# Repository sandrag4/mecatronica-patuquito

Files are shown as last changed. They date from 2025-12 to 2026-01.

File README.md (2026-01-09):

#  Proyecto de Mecatrónica – *Patuquito*

Este repositorio contiene todo el material necesario para el desarrollo del proyecto de la asignatura de Mecatrónica, cuyo objetivo es diseñar, montar y programar un **robot autónomo con patas**, capaz de **desplazarse y evitar obstáculos**.

El contenido está organizado para que cualquier usuario pueda **replicar**, **comprender** y **utilizar** el robot, ya sea con fines académicos o recreativos.

---

## Estructura del Repositorio

En las siguientes carpetas encontrarás todos los recursos del proyecto:

- [`codigo/`](./codigo/)  
  Contiene todos los códigos desarrollados durante el proyecto. Dentro de esta carpeta se incluyen:

  - [`codigo_robot/`](./codigo/codigo_robot/)  
    Código final utilizado por el robot para ejecutar los distintos modos de funcionamiento y comportamientos programados.

  - [`codigo_validaciones/`](./codigo/codigo_validaciones/)  
    Conjunto de códigos destinados a realizar las distintas pruebas y validaciones del robot, incluyendo test de motores, sensores, botones e inicialización.

- [`documentacion/`](./documentacion/)  
  Contiene los documentos generados durante el desarrollo del proyecto junto con los archivos de las piezas:  
  - **Informe de Autoevaluación** (diario de trabajo, problemas encontrados y soluciones aplicadas)  
  - **Informe Técnico** (documentación completa para replicar el proyecto en casa)  
  - **Manual del Usuario** (instrucciones para montar y utilizar el robot)  
  - **Manual de Mantenimiento** (indicaciones de cuidado y mantenimiento del sistema)
  - [`piezas/`](./documentacion/piezas)  
    Piezas para la impresión 3D
  - [`intentosde simulacion/`](./documentacion/intento_simulacion)  
    Los prototipos anteriores fallidos

- [`enunciado/`](./enunciado/)  
  Carpeta que contiene el enunciado completo del proyecto.

---
## Video

https://urjc-my.sharepoint.com/:v:/g/personal/s_calvo_2022_alumnos_urjc_es/IQALAh5Pe_J5TpLPzdulBIcyASQluEaZyc-CBJwZntN-4Jk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 

---

## Integrantes del Proyecto

- **Sandra González Alonso**  
- **Valeria Stobinski Adillo**  
- **Silvia Calvo Cabello**  
- **Irene Díez de Toro**

---

## Licencia y Uso

Este repositorio es **público** y de **libre acceso** para uso personal, educativo o recreativo.  
No está permitido su uso con fines comerciales ni su venta.

---

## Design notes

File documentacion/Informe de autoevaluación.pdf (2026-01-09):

# INFORME DE AUTOEVALUACIÓN

# PATUQUITO

# Mecatrónica

## IRENE DIEZ DE TORO

## SANDRA GONZALEZ ALONSO

VALERIA STOBINSKI ADILLO (https://www.aulavirtual.urjc.es/moodle/user/view.php?id=244258&course=237750)

## SILVIA CALVO CABELLO

## 4º INGENIERÍA ROBÓTICA SOFTWARE

12-12-2025

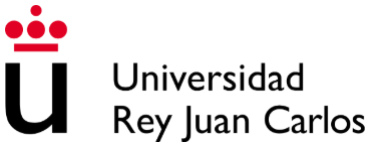
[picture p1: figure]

# Índice

Índice | 2
Planning Semanal | 4
Semana 29 - 9 | 4
- Búsqueda de robots con patas (Todas) | 4
Semana 5 - 10 | 4
- Primeros bocetos del robot (Todas) | 4
Semana 13 - 10 | 5
- Cálculo de motores, baterías y material necesario: (Silvia) | 5
- Distintos mecanismos del movimiento (Valeria y Irene) | 5
Semana 27 - 10 | 7
- Encontrar las baterías /pilas necesarias: (Silvia) | 7
- Diseño basico en blender sin mecanismo y probarlo en pybullet (preanálisis)
(Silvia, Sandra) | 7
- Diseño basico en blender con mecanismo y probarlo en pybullet (preanálisis)
(objetivo patucos) (Irene, Sandra, Valeria) | 7
- Diseño en blender de las piezas para imprimir (Sandra) | 8
- Diseñar cabeza y giro y hueco de la carga (Irene y Valeria) | 8
- Diseño del cableado (Silvia) | 9
Semana 3 - 11 | 9
- Planos mecánicos: (Sandra) | 9
Semana 10 - 11 | 9
- Programación patas: (Silvia) | 9
- Programación cabeza (Sandra) | 9
- Diseño eléctrico: (Irene y Valeria) | 9
Semana 17 - 11 | 10
- Programación: lógica del proyecto : (Sandra y Silvia) | 10
- Montaje del robot: (Todas) | 10
- Rediseño del engranaje: (Sandra) | 10
- Empezar con la documentación de los manuales (Silvia) | 10
Semana 24 -11 | 10
- Seguir con la documentación de los manuales (Silvia,Valeria,Irene) | 10
- Programación patas (Valeria y Sandra) | 11
- Rediseño de las patas (Valeria y Sandra) | 11
- Prueba de las pruebas (Sandra y Silvia) | 11
Semana 1-12 | 11
- Programación patas (Sandra) | 11
- Lijado de piezas (Todas) | 11
- Taladrar hueco para la segunda cabeza (Sandra y Valeria) | 12
- Diseño segunda cabeza (Irene) | 12
- Seguir con la documentación (Irene y SIlvia) | 12
- Programación segunda cabeza (Sandra) | 12
Semana 8-12 | 12
- Programación tocar pared (Sandra) | 12

- Planos restantes (Sandra y Silvia) | 13
Semana 15-12 | 13
- Terminar con la documentación (Irene y Silvia) | 13
Semana 5-1 | 13
- Terminar el montaje y pruebas (Sandra, Valeria, Irene, Silvia) | 13
Resumen | 14
1. Sandra González Alonso 9/10 | 14
2. Silvia Calvo Cabello 8/10 | 14
3. Valeria Stobinski Adillo 8/10 | 14
4. Irene Díez de Toro 8/10 | 15

# Planning Semanal

## Semana 29 - 9

- Búsqueda de robots con patas (Todas)
- Se realizó un estudio para investigar diferentes tipos de robots con patas. Sin embargo, muchos de ellos requerían un gran número de motores por pata, lo que resultaba en sistemas complejos y menos eficientes. A continuación se presentan algunos ejemplos:
- 1. Robots tipo perro
Ejemplo: Perro robótico Unitree Go2 Pro
Este tipo de robot tiene 3 grados de libertad en cada pata, lo que significa que necesita un total de 12 motores para el movimiento. Este número de motores, aunque efectivo, resulta ser excesivo y difícil de manejar en términos de eficiencia y diseño.
- 2. Robots tipo araña
Ejemplo: Araña robótica
Al igual que el robot tipo perro, el robot tipo araña también tiene 3 grados de libertad en cada pata, sumando un total de 12 servomotores para las 4 patas. Aunque el diseño permite una gran flexibilidad, el alto número de motores sigue siendo un desafío en términos de peso y consumo de energía.
- 3. Patas y arquitectura propuesta por Valeria
En este caso, se optó por un diseño basado en un sistema de patas que optimiza el número de motores, manteniendo la versatilidad y estabilidad del robot, pero con menos componentes. https://www.youtube.com/watch?v=iVVLTqdiBNI
- Enfoque hexápodo
Después de analizar estos diseños, decidimos optar por un enfoque basado en el movimiento hexápodo, tal como se muestra en el siguiente video. Este diseño permite controlar el movimiento de la estructura con un solo motor, lo que a su vez facilita el control de dos ejes de movimiento simultáneamente. Esto no solo reduce el número de motores necesarios, sino que mejora la eficiencia y la simplicidad del sistema en comparación con los enfoques previos.

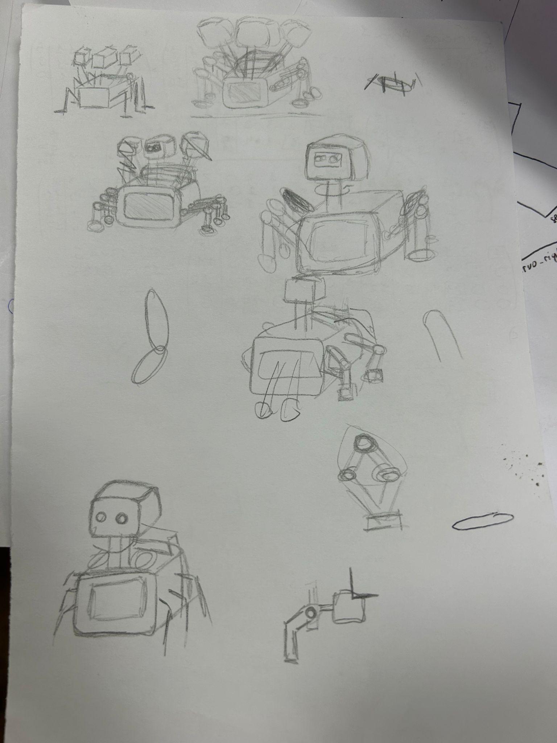
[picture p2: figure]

## Semana 5 - 10

- Primeros bocetos del robot (Todas)
La idea inicial era diseñar unas patas móviles, pero al analizarlo vimos que se requería un control demasiado complejo y un número elevado de motores para lograr el movimiento deseado. Por ello, se optó por adoptar un desplazamiento similar al de los escorpiones, utilizando cinco patas para aumentar la estabilidad. A partir de esta decisión se elaboraron los bocetos correspondientes al nuevo sistema.

En este diseño, las patas podían ser fijas y el movimiento dependía de la coordinación de tres pares, organizados en dos grupos que se desplazan de forma síncrona pero con un desfase entre ellos.

En cuanto a la cabeza, para facilitar en análisis del entrono, se querían hacer 3 cabezas. Primero era hacer 3 lineales, después se intentó desplazarlas hacia los lados y hacia atrás. A final con un sistema de rotación de cabeza y para tener más espacio en la tapa para el resto de piezas se optó por mantener solo una cabeza.

## Semana 13 - 10

- Cálculo de motores, baterías y material necesario: (Silvia)
- Se calcularon los motores. Se hicieron varios cálculos y mecanismos de engranajes debido a la disponibilidad de motores que había. Primero calculamos para 6 motores, y un motor por cada pata, luego hablando con el profesor volvimos a calcular los motores para que cada motor soporte 3 patas y un mecanismo de engranajes para moverlos, pero no tenían motores suficientemente potentes para ello. Por lo que volvimos a usar 6 servomotores para facilitar la sincronización de estos.
- Distintos mecanismos del movimiento (Valeria y Irene)

Tras definir el sistema de pares síncronos con desfase (el “sistema escorpión”), se analizó cómo lograr la coordinación del movimiento. Inicialmente se planteó utilizar seis servomotores. Sin embargo, comprobamos que no era necesario un sistema con retroalimentación continua, sino simplemente una coordinación por grupos.

Para reducir el número de motores, se estudió la posibilidad de emplear un mecanismo de engranajes accionado por dos motores, uno a cada lado. No obstante, tras realizar los cálculos y consultar con el responsable del material, se confirmó que no había disponibles motores con la potencia suficiente para este sistema.

Por ello, se decidió volver a la idea original de utilizar seis servomotores, que permiten obtener retroalimentación para una mejor coordinación de las patas, al ser completamente independientes entre sí.

Sistema de engranajes con espaciado y rotación de patas con limitación de movimiento en los ejes

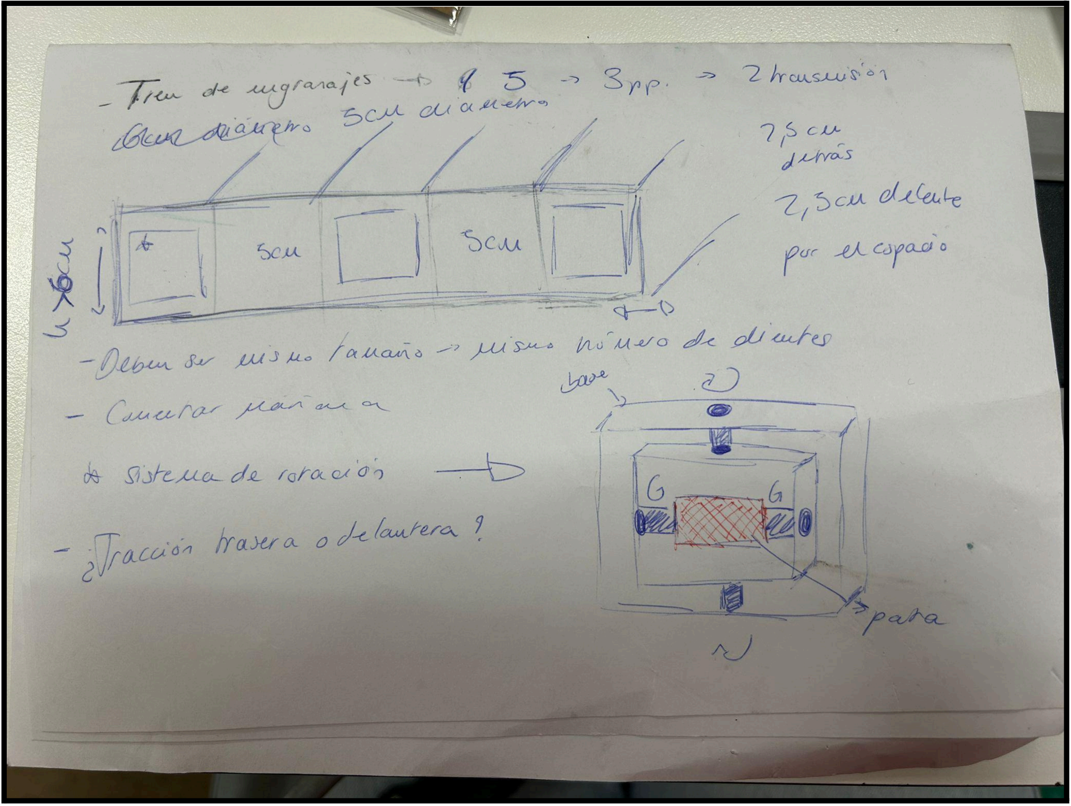
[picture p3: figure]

Diseño del sistema de enganche de pata con engranajes:

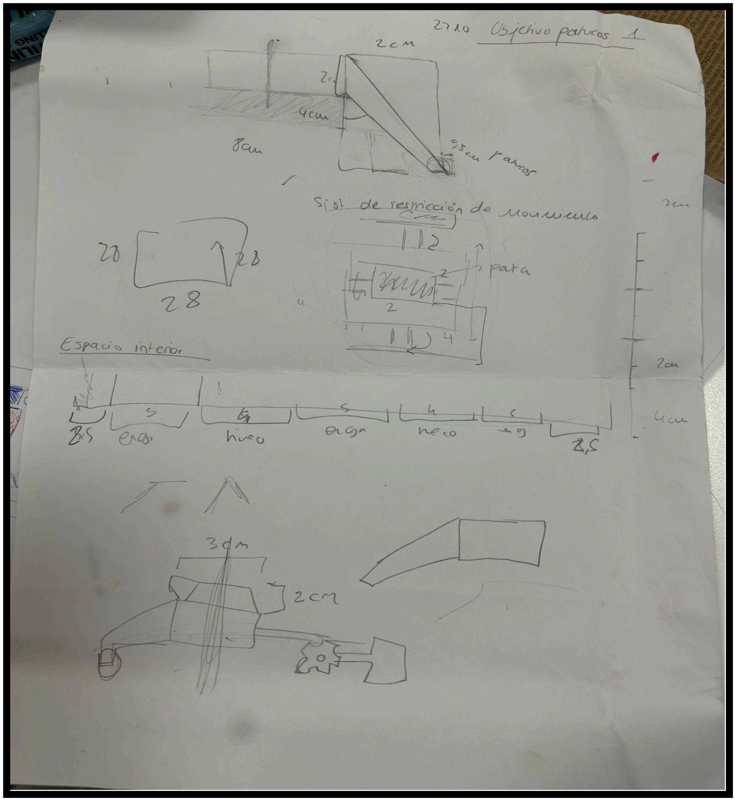
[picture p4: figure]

## Semana 27 - 10

- Encontrar las baterías /pilas necesarias: (Silvia)
- Se calcularon las baterías necesarias para todos los motores y se decidió comprar pilas recargables ya que las baterías necesarias eran de plomo y pesaban demasiado. 6 pilas de 1.2 V
- Diseño basico en blender sin mecanismo y probarlo en pybullet (preanálisis) (Silvia, Sandra)
- No funciona bien porque con un solo servo la pata movía su orientación y necesitábamos que mantuviese orientación del pie de la pata hacia el suelo siempre, conseguimos eso en Blender pero solo poniendo un motor extra que girase en dirección contraria para contrarrestar el giro. La otra solución fue que la pata no estuviese fija al motor y tuviese holgura, el problema de eso es que esa holgura daba demasiada libertad a la pata y se quedaba la pata en horizontal.
- Videos: video1.mp4 (https://urjc-my.sharepoint.com/:v:/g/personal/s_calvo_2022_alumnos_urjc_es/EeDAGlk2rV1Dtp-OM11wCsABKgBpXJ1iR6urnx2pbYHk5w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) video2.mp4 (https://urjc-my.sharepoint.com/:v:/g/personal/s_calvo_2022_alumnos_urjc_es/EaXeEfbVReZFqrjpIT3TwOIBPuNwsKoTI84sSxCdLMh5IQ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)
- Diseño basico en blender con mecanismo y probarlo

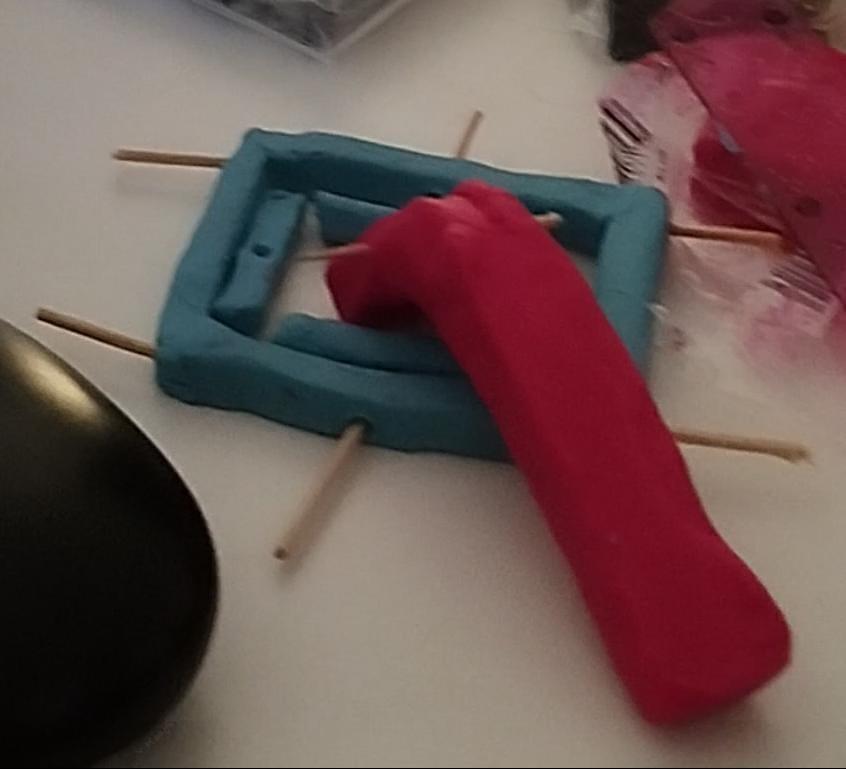
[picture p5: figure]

en pybullet (preanálisis) (objetivo patucos) (Irene, Sandra, Valeria)
- Para poder visualizar espacialmente el diseño 3D, se
compró plastilina con el fin de poder hacer un diseño
inicial de algunas piezas, principalmente las patas y
su mecanismo. Se probó y cambió las medidas de las patas, y de los mecanismos para dejar hueco suficiente para el movimiento de las patas. Una vez

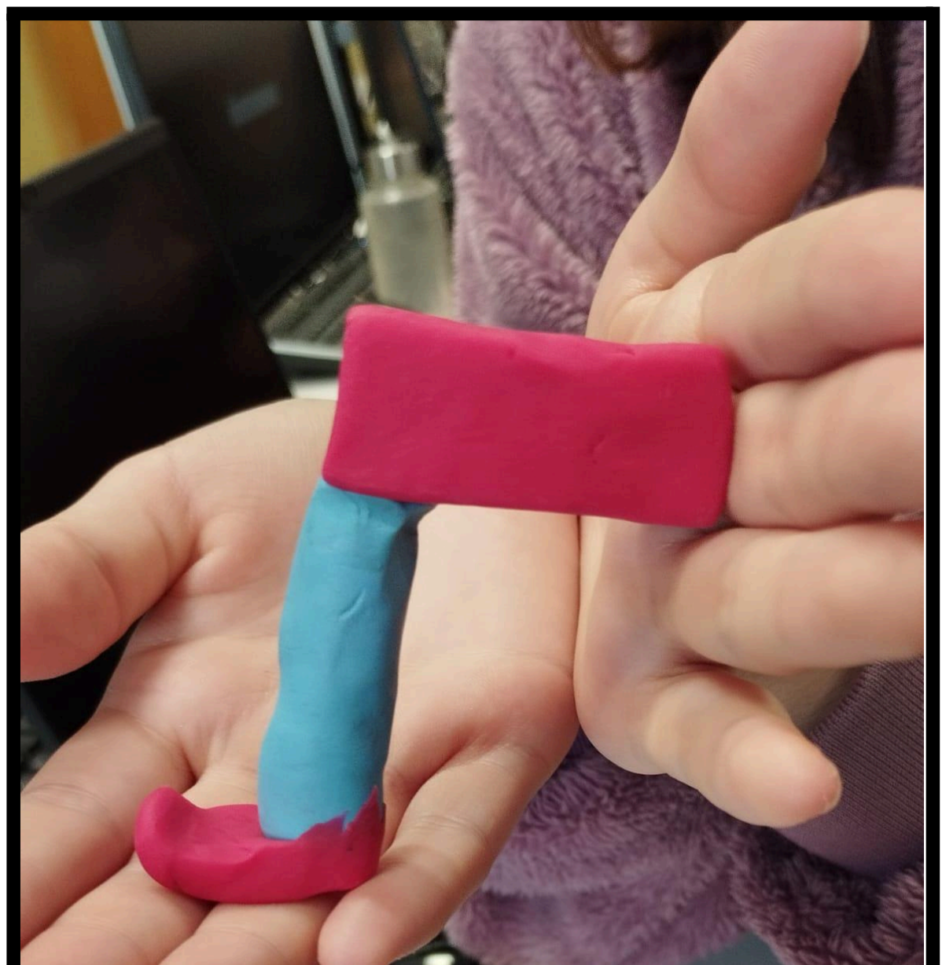
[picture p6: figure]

establecidas unas medidas específicas, después de este proceso, se fueron diseñando estas piezas en blender para probar su funcionamiento.
- Conseguir averiguar como hacer el mecanismo real en blender (teniendo que usar muchos más joints entremedias, por ello no podíamos realizar la simulación correctamente para obtener las gráficas) (Silvia)

Las imágenes adjuntas muestran el primer modelo para el engranaje y el primer diseño físico de la pata.

- Diseño en blender de las piezas para imprimir (Sandra)
- Diseño y rediseño de piezas para que el mecanismo pudiera tener espacio suficiente para moverse y para que cumpliera con las medidas, la plastilina ayudó bastante para visualizar como iban a quedar algunas piezas.
- Diseñar cabeza y giro y hueco de la carga (Irene y Valeria)

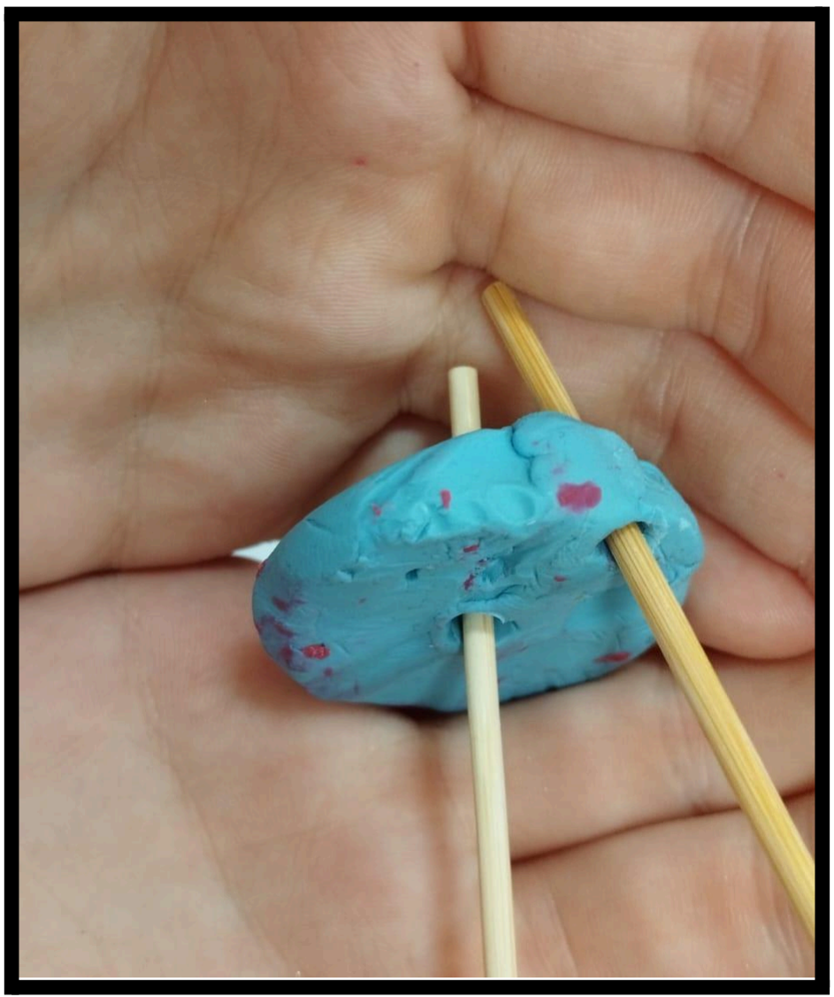
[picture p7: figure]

- Inicialmente, como se puede observar en los bocetos iniciales, para la parte superior del robot se consideró un diseño basado en tres cabezas con sus respectivos cuellos, basado en el mito griego de Cerbero. Tras varias deliberaciones, optamos por solo dejar una única cabeza funcional para poder montar el sensor láser en esta misma. En un principio, consideramos usar un sensor láser que nos proporcionaban los técnicos, pero tras darnos cuenta que no teníamos ningún cable para el uso de este, decidimos cambiarlo por el sensor ultrasonidos. Por otro lado, para poder simular los datos que recibiríamos de un sensor láser 360, optamos por hacer un cuello movible que girase de un lado a otro a través de un servo. En blender, diseñamos dos cabezas con dos distintos agujeros dependiendo del sensor (porque aún no nos habíamos decidido), una tapa para la cabeza (para poder meter al sensor en la cabeza) y un cuello que albergaría el servo que rotase las cabeza. Tras hacer comprobaciones de medidas, vimos que se nos pasaba el límite de altura, por ello tuvimos que rediseñar el concepto de la cabeza, eliminando el cuello y optando por meter el servo mayormente entre el cuerpo y la tapa. En cuanto a los cables, diseñamos un hueco en la parte trasera de la cabeza para poder pasarlos.
Por otra parte, para diseñar la bandeja para la carga, miramos las medidas y optamos por hacer una bandeja.
- Una vez impresas las piezas hubo un par de cambios. Por un lado, cuando metimos el sensor en la cabeza y los cables, nos dimos cuenta de que no cambian los cables debido a las clavijas, por ello, en la tapa taladrados un agujero rectangular y decidimos poner los cables de forma que estéticamente parecieran unas orejas en la cabeza. Por otra parte, el agujero de los ojos se nos quedó un poco justo de separación, por ello tuvimos que limar ligeramente uno de los ojos para que el sensor de ultrasonido encajase correctamente. En cuanto a encajar cada componente encima del robot, se opto por un sistema que hemos denominado “señor patata”, que consiste en encajar la bandeja de carga y demás componentes con velcro, con el fin de poder reajustarlo a gusto.
- Diseño del cableado (Silvia)
- Problemas con que las baterías sale un conector directo al arduino, pero necesitamos puentearlo y que aparte del arduino vaya a los motores. Usamos arduino mega porque como los servos son con realimentación necesitamos 6 pines pwm y 6 de interrupción hardware.

## Semana 3 - 11

- Planos mecánicos: (Sandra)
- Se obtuvieron los planos mecánicos de todas las piezas diseñadas para el robot. Para ello se importaron las mallas (en 3mf, en stl no funcionaba), conversión a solido, creación de vistas y acotación
- Se crearon los archivos para mandar a imprimir. Para ello, se exportaron archivos a stl, se pusieron las piezas en prusaSlicer, y tuvimos problemas con las unidades (la unidad de prusaSlicer son los milímetros y detectaba que algunas piezas en metros y otras en pulgadas cuando todas las piezas estaban en metros), al final conseguí escalarlas correctamente.

## Semana 10 - 11

- Programación patas: (Silvia)
- Para programar los servos de 360° utilicé una librería libre de derechos. Sin embargo, tenía dos inconvenientes: primero, era estática, así que solo permitía controlar un servo; y segundo, era bloqueante, ya que mientras el motor se movía, el programa quedaba esperando hasta que el servo alcanzara la posición. Por eso decidí modificar la librería para adaptarla a nuestro proyecto. Además, creé una interfaz muy sencilla de usar, con funciones específicas para avanzar, girar a la izquierda y girar a la derecha.
- Programación cabeza (Sandra)
- Programación del sensor ultrasonidos con el servo simulando el giro de cabeza mediante freertos para luego combinarlo con las patas (con arduino uno para la programación en paralelo con las patas)
- Diseño eléctrico: (Irene y Valeria)
- Pasarlo a limpio usando Fritzing. Una dificultad que tuvimos al respecto fue que en este no existía el modelo de los motores que íbamos a usar para el mecanismo de las patas. Por lo tanto, tuvimos que usar un motor parecido pero que solo poseía tres conectores y lo modificamos para que tuviera 4.

## Semana 17 - 11

- Programación: lógica del proyecto : (Sandra y Silvia)
- En un principio pensamos usar freertos para hacer que las tareas se ejecutarán con cierta periodicidad. Pero más adelante nos dimos cuenta de que eso no simplifica el código, sino que lo complicaba ya que había funciones bloqueantes, otras que solo podía entrar una vez… Por lo que decidimos hacer un código secuencial tradicional. Pudiendo elegir el modo de uso, prueba 1 o prueba 2 antes o al finalizar cada prueba.
- Montaje del robot: (Todas)
- Ya impresas todas la piezas nos pusimos a montar el robot, teniendo varios, varios, problemas:
■ No había espacio por donde pasar los cables de los motores en la base. Por lo que tuvimos que irnos al taller de arquitectura y con la ayuda del profesor técnico de ese laboratorio, aprendimos a usar varias herramientas como el taladro con sujeción que nos permitió hacer un agujero que atravesaba casi toda la base por en medio para dejar hueco a los cables entre bloques. Y a continuación tuvimos que hacer los agujeros para los cables de cada motor, fuimos perfeccionando nuestra técnica según avanzábamos
■ Las patas se daban con los motores al girar, por lo que esto supuso que teníamos que lijar las patas para acortarlas, pero esto hacía que se salieran de los cilindros por lo que tuvimos que volver a rediseñar estos.
■ Los servomotores no van bien los 6 a la vez. Tuvimos problemas por cómo programar los 6 servos, porque solo un servo funcionaba, dos, más o menos, más se entorpecían entre ellos.
- Rediseño del engranaje: (Sandra)
○
- Empezar con la documentación de los manuales (Silvia)
- Se inició la elaboración de la documentación correspondiente a los distintos manuales del proyecto. Durante esta fase, se avanzó significativamente en el informe técnico, estructurando su contenido y generando un índice preliminar tanto para el Manual del Usuario como para el Manual de Mantenimiento.

## Semana 24 -11

- Seguir con la documentación de los manuales (Silvia,Valeria,Irene)
- El equipo continuó con el desarrollo de la documentación pendiente.Se completaron varias secciones de este propio informe técnico y se avanzó notablemente en la redacción del Manual del Usuario, dejando la mayor parte del contenido finalizado.

- Programación patas (Valeria y Sandra)
- Durante esta semana se produjo un relevo interno de tareas: Silvia dejó de trabajar en la programación de los motores, y Valeria y Sandra asumieron la responsabilidad de continuar con esta parte del proyecto.
- El objetivo principal de esta reasignación era abordar la programación del sistema de locomoción desde una perspectiva diferente, buscando identificar posibles errores, mejorar la comprensión del mecanismo y optimizar la secuencia de movimiento de las patas.
- Rediseño de las patas (Valeria y Sandra)
- Tras varias pruebas, se detectó que la geometría inicial de las patas, aunque funcional en términos de altura, presentaba un problema de contacto con la parte inferior del chasis. Las patas rozaban con la estructura de la base, generando fricción y afectando la movilidad del robot.
- Como resultado, se procedió al rediseño completo del conjunto mecánico, realizando los siguientes cambios:
■ Se aumentó la distancia lateral de las patas para evitar el rozamiento con el chasis.
■ Se modificó la inclinación del segmento principal para mejorar la estabilidad dinámica.
■ Se rediseñó totalmente la pieza del pie, sustituyendo la forma original por un diseño esférico con un hueco que permite acoplar un “patuco” o zapato adicional.
- Este rediseño mejoró la maniobrabilidad, redujo el desgaste mecánico y aportó mayor comodidad para intercambiar o modificar los elementos de apoyo del robot.
- Prueba de las pruebas (Sandra y Silvia)
- SIn patas y sin motores

## Semana 1-12

- Programación patas (Sandra)
- Implementar la lógica para que las patas se muevan de acuerdo a las señales de los sensores y las órdenes del controlador.
- Ajustar la velocidad y la precisión del movimiento para asegurar que las patas puedan moverse con la fluidez y estabilidad necesarias durante las pruebas.
- Lijado de piezas (Todas)
- Mejorar el acabado de las piezas impresas en 3D para garantizar que encajen correctamente en el ensamblaje final y evitar cualquier interferencia con el movimiento del robot.

Tareas:

- Lijar todas las piezas impresas para eliminar cualquier exceso de material y suavizar las superficies.
- Limpiar las piezas de manera adecuada para eliminar restos de polvo o residuos de la impresión 3D.
- Asegurarse de que todas las piezas tengan un buen acabado estético y funcional.
- Taladrar hueco para la segunda cabeza (Sandra y Valeria)
- Modificar la estructura del robot para agregar una segunda cabeza en la parte inferior de la base, con el fin de mejorar el rendimiento durante las pruebas de obstáculos debido a que la cabeza de la primera prueba es muy alta para detectar los obstáculos.
- Diseño segunda cabeza (Irene)
- Rediseñar la cabeza del robot para que sea más baja y evitar que choque con el suelo durante las pruebas.
- Seguir con la documentación (Irene y SIlvia)
- Continuar con la documentación técnica del proyecto, especialmente el informe de progreso y la documentación del montaje.
- Programación segunda cabeza (Sandra)
- Programar el funcionamiento de la segunda cabeza del robot, asegurándose de que no interfiera con las patas.
Tareas:
- Implementar la lógica que permita que la segunda cabeza gire, pero sin llegar a los ángulos de 0° y 180°, ya que esos ángulos podrían generar interferencias con las patas.
- Configurar los sensores para que la segunda cabeza detecte correctamente los obstáculos sin chocar con ellos.
- Realizar pruebas para verificar la efectividad de la segunda cabeza en las distintas situaciones y ajustar la programación según sea necesario.

## Semana 8-12

- Programación tocar pared (Sandra)
- Cambio de la manera de reconocer la pared debido a que antes la detectaba a 25 cm, y ahora requería reconocerla a unos 5, para ello se acerca a la pared, indica que es pared y retrocede para poder girar.

- Planos restantes (Sandra y Silvia)
- Completar los planos técnicos de las piezas modificadas (segunda cabeza, patas, engranaje y base) para que puedan ser utilizados en la fabricación final o para futuras mejoras.

## Semana 15-12

- Terminar con la documentación (Irene y Silvia)
- Se ha completado la documentación del proyecto, quedando únicamente pendiente la fabricación de los componentes finales de las extremidades. Esta fase se encuentra temporalmente suspendida debido a una avería técnica en la unidad de impresión 3D utilizada.

## Semana 5-1

- Terminar el montaje y pruebas (Sandra, Valeria, Irene, Silvia)
- Tras la pausa por avería técnica terminamos de montar el robot con las nuevas piezas. Y colocar bien todo para realizar las pruebas

# Resumen

### 1. Sandra González Alonso 9/10

Sandra ha tenido un rol transversal muy activo, destacando especialmente en el diseño CAD, la generación de planos y la programación lógica y de componentes.

- Diseño y Mecánica: Se encargó del diseño en Blender de las piezas para imprimir , así como de la obtención de los planos mecánicos, la conversión a sólidos y la resolución de problemas de escalado en el software de impresión. Además, realizó el rediseño del engranaje y, junto a Valeria, rediseñó las patas tras detectar problemas de rozamiento con el chasis, implementando un diseño esférico para el pie.
- Programación: Programó el sensor de ultrasonidos y el servo de la cabeza utilizando FreeRTOS. Colaboró con Silvia en la lógica general del proyecto y posteriormente asumió la programación de las patas para optimizar la secuencia de movimiento. También desarrolló la programación de la segunda cabeza y la lógica para tocar la pared y retroceder.
- Montaje: Participó en el montaje, taladrando el hueco para la segunda cabeza y realizando pruebas de los sistemas.

### 2. Silvia Calvo Cabello 8/10

Silvia lideró la parte eléctrica inicial, la gestión de motores y baterías, y asumió la mayor parte de la carga de documentación, además de iniciar la programación de movimiento.

- Electrónica y Hardware: Realizó los cálculos de motores y baterías necesarios, seleccionando pilas recargables de 1.2V. Diseñó el cableado y gestionó las conexiones del Arduino Mega para los servos con realimentación.
- Programación: Inició la programación de las patas modificando una librería bloqueante para adaptarla al proyecto y creó una interfaz de movimiento. Trabajó en la lógica secuencial del proyecto junto a Sandra.
- Documentación: Fue la encargada principal de iniciar y estructurar la documentación de los manuales de usuario y mantenimiento, así como el informe técnico , labor que continuó hasta el final del proyecto junto con Irene.
- Diseño: Colaboró en el diseño básico inicial en Blender y las simulaciones en PyBullet.

### 3. Valeria Stobinski Adillo 8/10

Valeria aportó la arquitectura base del robot y fue fundamental en el diseño mecánico de los mecanismos de movimiento y el sistema eléctrico visual.

- Diseño Conceptual y Mecánico: Propuso la arquitectura de patas y el enfoque hexápodo que se utilizó finalmente. Trabajó junto a Irene en el análisis de mecanismos de movimiento. Participó en el diseño de la cabeza, el sistema de giro y el hueco de carga.
- Rediseño Crítico: Junto con Sandra, rediseñó las patas para corregir la fricción con la base, modificando la inclinación y creando el hueco para el "patuco".
- Electrónica y Montaje: Realizó el diseño eléctrico en limpio utilizando Fritzing, modificando componentes para adaptarlos a la realidad. Ayudó a taladrar el chasis para la segunda cabeza y participó en la programación de las patas en la fase de relevo.

### 4. Irene Díez de Toro 8/10

Irene se centró en el diseño estructural de la cabeza, los sensores y la carga, además de apoyar fuertemente en la documentación y el diseño eléctrico.

- Diseño 3D y Estructura: Trabajó en los mecanismos de movimiento y diseñó la cabeza original, el sistema de giro y la bandeja de carga, adaptando el diseño ("señor patata") para el sensor de ultrasonidos. Posteriormente, se encargó del diseño de la segunda cabeza para bajar el perfil del robot.
- Electrónica: Colaboró con Valeria en el diseño eléctrico y los esquemas en Fritzing.
- Documentación: Participó activamente en la redacción de los manuales y el informe de progreso junto a Silvia desde la semana del 24 de noviembre hasta el final

La puntuación no es perfecta debido a la falta de comunicación de todas y la falta de revisión y apoyo en todas las áreas debido a la gran variedad de trabajo.

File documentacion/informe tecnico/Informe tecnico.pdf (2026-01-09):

# INFORME TÉCNICO

# PATUQUITO

# Mecatrónica

## IRENE DIEZ DE TORO

## SANDRA GONZALEZ ALONSO

VALERIA STOBINSKI ADILLO (https://www.aulavirtual.urjc.es/moodle/user/view.php?id=244258&course=237750)

## SILVIA CALVO CABELLO

## 4º INGENIERÍA ROBÓTICA SOFTWARE

12-12-2025


# Indice

# Introducción

Este proyecto consiste en el diseño, montaje y programación de un sistema mecatrónico con el objetivo de aplicar y consolidar los conocimientos adquiridos durante la asignatura. En particular, se desarrolla un robot móvil hexápodo, capaz de realizar desplazamientos autónomos y ejecutar tareas específicas dentro de un conjunto definido de restricciones técnicas.

El robot emplea una configuración de seis patas que replica la locomoción de un insecto, adoptando un patrón de movimiento similar al de un escorpión. Tanto el diseño del mecanismo como la geometría de todas las piezas han sido desarrollados íntegramente para este proyecto, sin recurrir a componentes de diseño externo. La única referencia complementaria utilizada corresponde al vídeo demostrativo del funcionamiento, disponible en: https://www.youtube.com/watch?v=iVVLTqdiBNI

El proyecto integra todas las etapas fundamentales del desarrollo mecatrónico: desde el diseño conceptual y la planificación del sistema, pasando por la selección de actuadores y sensores, el diseño mecánico detallado, la integración electrónica y la programación embebida, hasta las fases de prototipado, fabricación, pruebas y validación del funcionamiento global.

## Descripción general del sistema

El sistema desarrollado es un robot hexápodo con una estructura modular que incorpora una tapa intercambiable, diseñada para permitir la instalación o sustitución de componentes adicionales, tales como cargas útiles u otros módulos funcionales. El robot emplea seis patas para su locomoción y está diseñado para cumplir tareas de navegación básica de forma autónoma.

El sistema integra actuadores, sensores y una placa de control que gestiona la coordinación del movimiento y la captación del entorno. La estructura mecánica está optimizada para mantener la estabilidad incluso cuando transporta una carga de hasta 250 gramos. Asimismo, el robot es capaz de realizar detección y evasión de obstáculos de manera autónoma. Además, incorpora una interfaz operativa sencilla que permite encender, apagar y cambiar el modo de funcionamiento durante las pruebas.

Una de las principales ventajas del diseño es su eficiencia mecánica: mediante un sistema de soportes específicamente desarrollado para este proyecto, un único motor es capaz de generar movimiento en dos ejes distintos. Esto simplifica el sistema, reduce el peso y minimiza el consumo energético sin sacrificar funcionalidad.

# Diseño mecánico

Para el desarrollo del diseño mecánico, el objetivo principal era lograr un sistema de locomoción que proporcionará la mejor movilidad y velocidad posible, manteniendo al mismo tiempo una estructura estable y de complejidad moderada. Tras analizar distintos tipos de mecanismos (y tomando como referencia la locomoción de diversos seres vivos) seleccionamos una solución que se ajustaba adecuadamente a los requisitos del proyecto. Nuestra elección se basó en un mecanismo inspirado en el movimiento de una hormiga, concretamente en una simulación que reproducía su comportamiento locomotor. Además, consultamos con el profesor para confirmar que la propuesta no resultara excesivamente compleja y comprender mejor su funcionamiento antes de proceder con el diseño. Durante el proceso de diseño y montaje también identificamos ciertos ajustes necesarios, que fuimos modificando con el fin de que el mecanismo encajará de forma óptima con nuestro concepto y respondiera correctamente a los objetivos planteados.

## Patas

1. ¿Por qué seis patas?

La elección del número de patas se determinó en función del modelo mecánico que habíamos planteado. Inicialmente consideramos utilizar únicamente cuatro patas; sin embargo, tras analizarlo con más detalle, concluimos que esta configuración reduciría significativamente la estabilidad del robot. Nuestro mecanismo requería además un par de patas centrales capaces de mantener la estabilidad general de la estructura y contribuir al equilibrio durante el ciclo de movimiento.
Por otra parte, para lograr una locomoción eficiente, era necesario que algunas patas se movieran antes que otras, lo que encaja de manera natural con una configuración de seis patas. Esta elección proporciona una estabilidad estática elevada, permitiendo que el robot se mantenga firme incluso cuando una o dos patas están en el aire gracias al soporte de un trípode estable. Asimismo, ofrece redundancia, de modo que el robot puede seguir avanzando aunque una pata falle. A ello se suma un mejor reparto del peso, especialmente útil en robots pequeños que cargan componentes como baterías o sensores, y un movimiento más fluido, ya que las seis patas permiten emplear ciclos de marcha alternados (gait tripod) que mejoran la tracción y la continuidad del desplazamiento.
2. ¿Por qué esa forma de patas? ¿Qué función desempeñan?

Dado que basamos nuestro diseño en la morfología de una hormiga, optamos por unas patas de forma estilizada y alargada que evocan dicha inspiración. No obstante, introdujimos una modificación importante: incorporamos una estructura similar a un “muñon”, ya que cada pata integra un patuco que mejora la estabilidad, reduce el riesgo de deslizamiento y aporta un acabado estéticamente más atractivo.
Las patas son largas y lo suficientemente anchas para elevar el robot y evitar que el cuerpo se arrastre por el suelo, pero sin excederse para no comprometer el peso ni el movimiento. Además, presentan un ángulo específico que impide que choquen con el chasis durante la marcha. Incluyen también un orificio destinado al paso de la barra que permite su movilidad.

En el extremo superior se encuentra un pequeño cilindro diseñado para encajar en el engranaje responsable de generar el giro de la pata. El conjunto se fabricó en PLA con un 10 % de relleno, lo que proporciona una resistencia adecuada para soportar el peso total del robot sin deformaciones estructurales. Por otro lado, la funcionalidad de estas consiste en transformar el movimiento rotacional (del engranaje/eje) en un movimiento de avance mediante una cinemática predefinida. Mantener contacto con el suelo en fases alternadas para sostener el peso y generar propulsión.

## Engranajes

1. ¿Por qué hemos usado engranajes?

Tras la elección del diseño de las patas, fue necesario definir el mecanismo encargado de su rotación y coordinación. Para este propósito, se decidió emplear un sistema de engranajes, ya que ofrece una transmisión eficiente y precisa del movimiento desde el motor hasta las patas del robot. Mediante este sistema es posible adaptar la velocidad de giro, permitiendo tanto la reducción como la multiplicación de la velocidad en función del par necesario, lo que resulta fundamental para asegurar un movimiento estable y con la fuerza adecuada durante el desplazamiento.

Además, el uso de engranajes facilita la sincronización del movimiento entre las patas pares e impares, garantizando que el robot mantenga un patrón de marcha coordinado y equilibrado. Esta sincronización es clave para mejorar la estabilidad y la eficiencia del movimiento, evitando deslizamientos o pérdidas de apoyo durante la locomoción.

Por otro lado, el sistema de engranajes destaca por su robustez, ya que se trata de un mecanismo mecánico relativamente simple, fiable y de fácil mantenimiento. Estas características lo convierten en una solución adecuada para un robot destinado a operar de forma continua, reduciendo la probabilidad de fallos mecánicos y prolongando la vida útil del conjunto.

2. ¿Por qué esa forma de engranajes?

Se eligió esta forma principalmente porque su geometría circular permite transmitir de manera eficiente y continua la rotación necesaria para el correcto funcionamiento de las patas. Este tipo de diseño facilita una distribución uniforme de las fuerzas durante el movimiento, lo que contribuye a un funcionamiento más suave y controlado. El componente presenta un grosor considerable, elegido deliberadamente para aumentar su resistencia mecánica y evitar posibles roturas o deformaciones cuando el sistema se encuentra sometido a esfuerzos prolongados o cargas elevadas.

Además, incorpora un orificio central destinado a la correcta fijación del motor junto con la pieza que lo sujeta, garantizando un acoplamiento firme, estable y bien alineado. Por otro lado, dispone de un segundo hueco diseñado específicamente para introducir la pieza de la pata que se conecta al mecanismo, permitiendo una unión segura y precisa que asegura una correcta transmisión del movimiento entre el motor y la pata.

## Mecanismo completo (patas + engranajes)

### 4.1. Justificación del mecanismo

Además de que la idea resultaba atractiva por su inspiración, este sistema de locomoción destaca por ser sencillo pero efectivo, lo que lo convierte en una solución ideal para prototipos educativos o de investigación. Su funcionamiento permite transformar la rotación continua del motor en un movimiento de avance mediante un ciclo mecánico previamente definido, facilitando la generación de un patrón de marcha estable sin necesidad de sistemas de control complejos.

Asimismo, este enfoque reduce significativamente la complejidad asociada al uso de servomotores independientes en cada articulación, simplificando tanto el diseño mecánico como el control del sistema. Por último, se trata de un diseño robusto, económico y fácil de mantener, características especialmente valoradas en proyectos experimentales o de desarrollo, donde la fiabilidad y la simplicidad son factores clave.

### 4.2. Cómo funciona el mecanismo

El motor transmite el movimiento de rotación al engranaje principal, que actúa como elemento central del sistema de transmisión. Este engranaje se encuentra directamente vinculado a las patas, de modo que su giro se traduce en el movimiento coordinado de estas. Gracias a la geometría específica de las patas, la rotación del engranaje genera un ciclo de movimiento que combina de forma alternada las fases de elevación y avance, permitiendo el desplazamiento del robot.

Además, las seis patas están organizadas para moverse en fases alternadas, lo que garantiza que siempre exista un número suficiente de apoyos en contacto con el suelo. Esta disposición asegura la estabilidad del sistema en todo momento, incluso durante el cambio de fase entre las patas, contribuyendo a un desplazamiento continuo y equilibrado.

* El montaje se encuentra adjunto en anexos.

# Diseño electrónico

## Descripción general

El robot se alimenta con un portapilas de 6 baterías AA. Estas pilas suministran energía tanto al Arduino Mega 2560 como a los servomotores y al resto de componentes. En el portapilas hay un interruptor que permite encender y apagar el robot, y un LED verde indica cuando está encendido.

Una vez encendido, el robot tiene dos botones para elegir el modo de funcionamiento. Cada modo se indica con un LED de color diferente. Todos los componentes están conectados al Arduino excepto los seis servomotores de las patas, que van alimentados directamente por las pilas debido a su consumo.

Se eligió un Arduino Mega 2560 porque ofrece suficientes pines PWM para controlar los seis servomotores Parallax Feedback 360º que usa el robot para las patas.

* Los planos y los calculos eléctricos se encuentran adjuntos en anexos.

# Diseño software

El software del robot ha sido desarrollado siguiendo una arquitectura secuencial basada en estados, integrando lectura de sensores, control de actuadores y gestión de modos de operación. En esta sección se describen los elementos principales del diseño lógico, incluyendo el sistema de indicadores luminosos, la lógica general de funcionamiento y los modos disponibles.

## Interfaz Gráfica y de Usuario

La interfaz de usuario del robot está compuesta por un conjunto de elementos físicos diseñados para proporcionar información visual del estado del sistema y permitir la selección manual de los modos de funcionamiento. Estos elementos ofrecen una interacción simple, directa y adecuada para las pruebas y validación del dispositivo.

### Indicadores luminosos

El robot incorpora tres indicadores luminosos (LEDs) que informan sobre el estado operativo y sobre el modo activo. Estos elementos proporcionan retroalimentación visual inmediata tanto durante la fase de inicialización como durante la operación normal del sistema..

Led Color | Estado / Modo asociado | Descripción funcional
Verde | Estado Operativo | Se enciende al completar la secuencia de inicio. Confirma la correcta inicialización del sistema y que coloque las patas en su postura de arranque.
Azul | Modo 1: Seguimiento de Pared | Indica que el robot está ejecutando el modo de seguimiento de pared, avanzando paralelo a una superficie sin evasión de obstáculos.
Amarillo | Modo 2: Exploración con Evitación de Obstáculos | Señala que el robot está ejecutando el modo de exploración; detecta paredes y obstáculos y realiza maniobras autónomas de evasión.

### Control del robot

El sistema dispone de una interfaz de control básica compuesta por:
Dos botones físicos, cada uno destinado a la selección de uno de los modos de funcionamiento del robot.
El robot dispone de un sistema de control por radio para seleccionar el modo de trabajo de forma inalámbrica mediante el móvil.
- Botón 1 → Activación del Modo 1: Seguimiento de Pared

- Botón 2 → Activación del Modo 2: Exploración con Evitación de Obstáculos

Un interruptor principal, ubicado en el portapilas, que permite encender o apagar el robot de manera segura. Este interruptor garantiza que la alimentación se pueda cortar sin riesgo para los servomotores ni para la electrónica, y previene activaciones involuntarias durante el manejo o el transporte.

## Descripción general del funcionamiento

Tras encender el robot, el sistema inicia un proceso de inicialización destinado a preparar la mecánica de locomoción. Durante esta fase, coloque el robot en el suelo asegurándose de que las patas estén en la posición correcta: hacia abajo (delantera derecha, trasera derecha e izquierda central) y hacia arriba (delantera izquierda, trasera izquierda y derecha central). Una vez superada esta etapa, el robot queda a la espera de la selección de un modo de funcionamiento mediante los botones disponibles en la interfaz física. Cuando el usuario pulsa uno de los botones:

1. Se ilumina el LED correspondiente al modo escogido.
2. El robot ejecuta el comportamiento asociado a dicho modo.

### 3. Al finalizar, vuelve al estado de espera, permitiendo seleccionar nuevamente el

mismo modo o un modo distinto.

Los modos de funcionamiento implementados son los siguientes:

## Modo 1: Seguimiento de Pared

El Modo 1 permite al robot seguir una pared a lo largo de un recorrido aproximado de un metro.

Principio de funcionamiento

El robot utiliza su sensor ultrasónico para medir continuamente la distancia entre él y la pared. Periódicamente compara la distancia recibida con un valor de referencia.
En función del resultado:
- Si se acerca demasiado → ajusta su trayectoria alejándose ligeramente.
- Si se separa más de lo previsto → corrige para acercarse nuevamente.
- Si la distancia permanece estable → continúa avanzando recto.
De esta manera, el robot mantiene su paralelismo con la pared durante todo el recorrido.

Limitación importante

Este modo no incorpora detección de obstáculos ajenos a la pared.

Cualquier objeto en la trayectoria será interpretado como una prolongación de la pared, y el robot avanzará sin aplicar maniobras evasivas.

## Modo 2: Exploración con Evitación de Obstáculos

El Modo 2 permite al robot recorrer el entorno siguiendo una secuencia de exploración estructurada, mientras realiza detección y evasión activa de obstáculos.

Secuencia de exploración

1. Avanzar hacia el frente: El robot se desplaza en línea recta desde su posición inicial hasta detectar la pared frontal.
2. Primer giro de 90°: Al alcanzar la pared, ejecuta un giro de 90° hacia la derecha para orientarse hacia el siguiente límite.
3. Desplazamiento lateral: Se desplaza hacia la pared lateral derecha hasta entrar en contacto o detectarla.
4. Segundo giro de 90°: Realiza un nuevo giro de 90° para dirigirse hacia la pared posterior (zona inferior del plano).
5. Tercer giro de 90°: Al llegar a la pared inferior, gira nuevamente 90° hacia la izquierda para encarar el último tramo.
6. Cierre del perímetro: Avanza hacia la última pared restante para completar el recorrido total de exploración.

Esta secuencia permite cubrir las cuatro paredes del entorno de forma sistemática.

Evasión de obstáculos

Para la navegación, el robot emplea un sensor de ultrasonidos con un barrido oscilante de ±15°, simulando el funcionamiento de un sistema LiDAR para el mapeo de proximidad.

### 1. Discriminación de Objetos

El sistema diferencia entre una pared y un obstáculo mediante una validación de doble sensor:

- Pared: Se confirma si el sensor de ultrasonidos superior detecta presencia simultánea, indicando una superficie de altura continua.
- Obstáculo: Se identifica cuando el sensor inferior detecta un objeto pero el superior tiene el campo libre, permitiendo así iniciar la maniobra de evasión.

### 2. Protocolo de Evasión

Una vez detectado un obstáculo, el robot ejecuta automáticamente la siguiente secuencia:

1. Análisis de espacio: El sistema evalúa la disponibilidad de espacio en el flanco derecho; si se detecta un bloqueo, se opta por la evasión por la izquierda.
2. Giro de flanqueo: Ejecuta un giro de 90° en la dirección de escape seleccionada.

3. Sobrepaso: Avanza una distancia predeterminada para garantizar que ha superado el eje del obstáculo y dispone de espacio suficiente para maniobrar.
4. Reincorporación: Realiza un segundo giro de 90° para alinearse nuevamente con su trayectoria original.
5. Reanudación: El robot retoma su recorrido normal tras confirmar que el obstáculo ha sido esquivado con éxito.

## Librerías utilizadas

El software se ha desarrollado utilizando las herramientas estándar del entorno Arduino. En particular:
Se emplea la librería Servo.h para el control de los servomotores.
El movimiento del robot se controla mediante la función servo.write(), que permite ajustar la posición de los servomotores en función de los valores que se le asignen. Se utilizan tres valores principales para controlar la dirección y la velocidad de los motores:
- Velocidad > 90 : Este valor hace que el motor gire en una dirección a alta velocidad.
- Velocidad 90 (paro): Cuando el valor es 90, los motores se detienen completamente, lo que provoca el paro de las patas o el movimiento en la dirección actual.
- Velocidad < 90: Este valor hace que el motor gire en la dirección contraria a la de la velocidad > 90, permitiendo que el robot retroceda o cambie de dirección.

Además, para asegurar que los motores se mantengan sincronizados y el movimiento sea fluido, se cuenta el número de vueltas que da cada motor mientras gira. Esto permite ajustar la sincronización de las patas o movimientos para evitar desajustes y asegurar que el robot se mueva de manera coordinada, manteniendo la estabilidad y el control durante las operaciones.

Este sistema de control de velocidad y seguimiento de las vueltas de los motores es crucial para garantizar que el robot responda de forma precisa a los comandos y que cada parte del movimiento se ejecute con la sincronización adecuada.

*Las pruebas realizadas se encuentran adjuntas en anexos.

# Oportunidades de mejora y trabajos futuros

Se deben corregir el tamaño de la base para que las patas no se choquen, además de seleccionar unos servomotores más potentes o hacerlo con dos servomotores aún más potentes pero con el mecanismo de sincronización de todas las patas de un lado.

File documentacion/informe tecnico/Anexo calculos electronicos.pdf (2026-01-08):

## Componentes electrónicos principales

- Arduino Mega 2560
- 6 servomotores parallax feedback 360º
- 2 servomotores SG90
- 2 sensores ultrasonidos
- 1 led verde
- 1 led azul
- 1 led amarillo
- 3 resistencias 220 Ohm (para los leds)
- 2 resistencias 220 Ohm (para los botones)
- 2 botones
- 1 portapilas AAx6 con terminal jack
- 6 pilas recargables AA 1.2V/pila 2.6 A/pila
- Cables macho - macho para las uniones

## Cálculos y elección de componentes

Cálculo servomotores:
Datos: Radio de las patas 2.5 cm con una carga 1.5 kg queriendo obtener una velocidad lineal mínima de 0.1 m/s
Min revoluciones: ω = V / r = 0.1 / 0.025 = 4 rad/s → RPM = (4 * 60) / (6.283) = 38 RPM Fuerzas: F = m * g = 1.5 * 9.81 = 14.72 N → Ff = µ * F = 0.3 * 14.72 = 4.41 N
Par: τ = Ff * r = 4.41 * 0.025 = 0.11025 N·m
Factor de seguridad: τ = 0.11025 N·m * 1.3 = 0.143325 N·m

Los servos elegidos: 120 RPM y 0.25 N·m
Se usarán 6 motores debido a que quisimos hacerlo con 2 (3 patas cada servo), pero los servos disponibles no tenían par suficiente.

Cálculo baterías:
Cálculo de los Amperios:
I motores patas = 150 mA | I ultrasonido = 15 mA
I motor cabeza = 170 mA | I componentes electrónicos (leds…) = 65 mA
I arduino = 100 mA

I total = 150 *6 + 170 + 100 + 15 + 65 = 1.25 A durante 4 horas → 1.25 * 4 = 5 A
Corriente en arranque pico = 1200 * 7 + 100 + 15 + 65 = 8.580 A
Tasa de descarga = 8.580/5 = 1.72
Necesitamos una batería con mínimo 5A y una tasa de descarga de 1.75. Optamos por una pilas recargables(6) para mayor accesibilidad y comodidad de 2.6 A cada una, obteniendo un total de 15.6 A

Voltaje: Los servomotores necesitan una alimentación de 6V pudiendo ser esta mayor, y el arduino mega una alimentación de 5 o 7-12 usando el regulador de voltaje. Por lo que 6 pilas de 1.2 V cada una ofrecía un voltaje de 7.2 V, perfecto para ambos dispositivos.

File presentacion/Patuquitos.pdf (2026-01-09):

# Robot Patuquitos

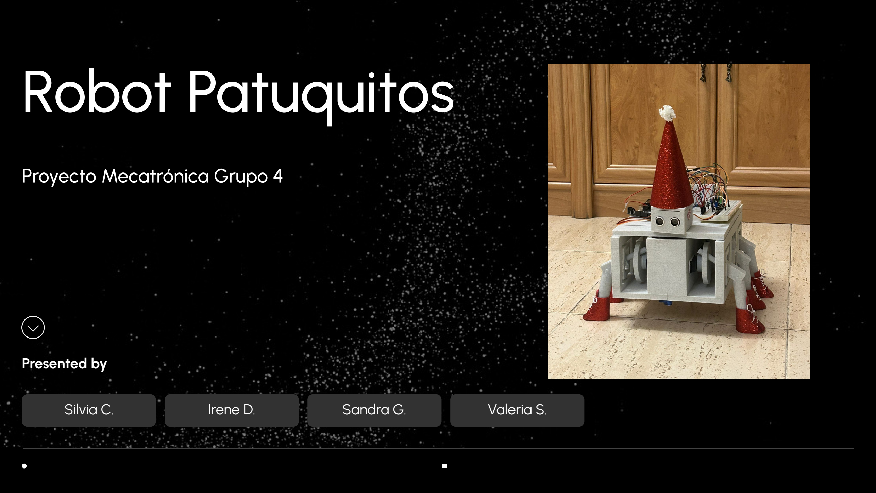
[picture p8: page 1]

Proyecto Mecatrónica Grupo 4

Silvia C. | Irene D.

Presented by

Sandra G. | Full Name 2 Valeria S.

Índice | 1

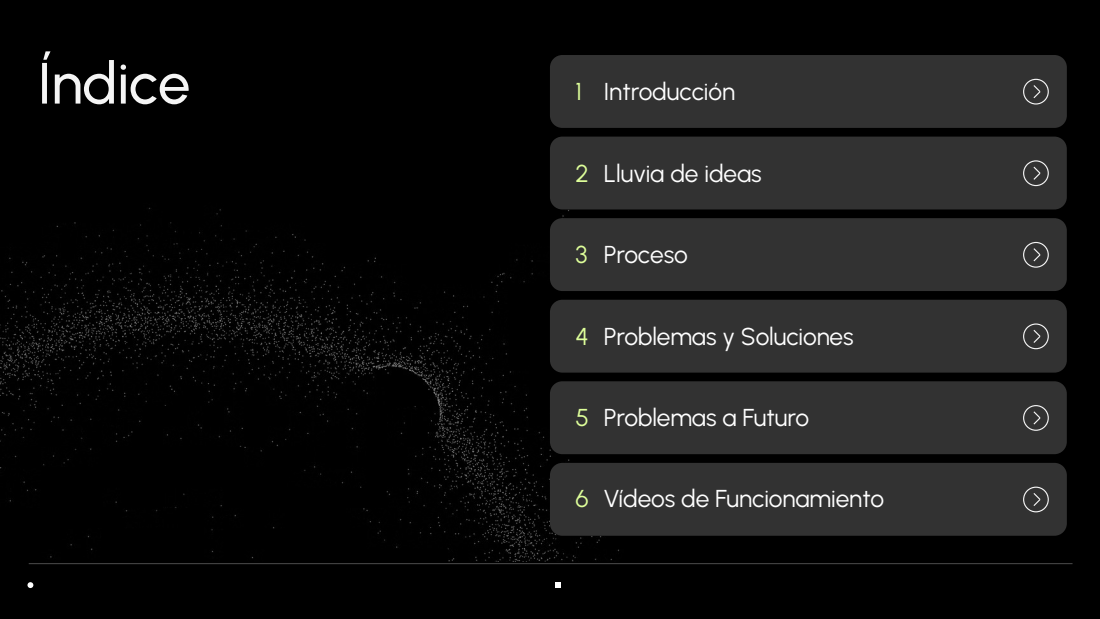
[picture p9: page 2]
Introducción; Proceso; Problemas y Soluciones; Problemas a Futuro

Lluvia de ideas

Vídeos de Funcionamiento

# Introducción

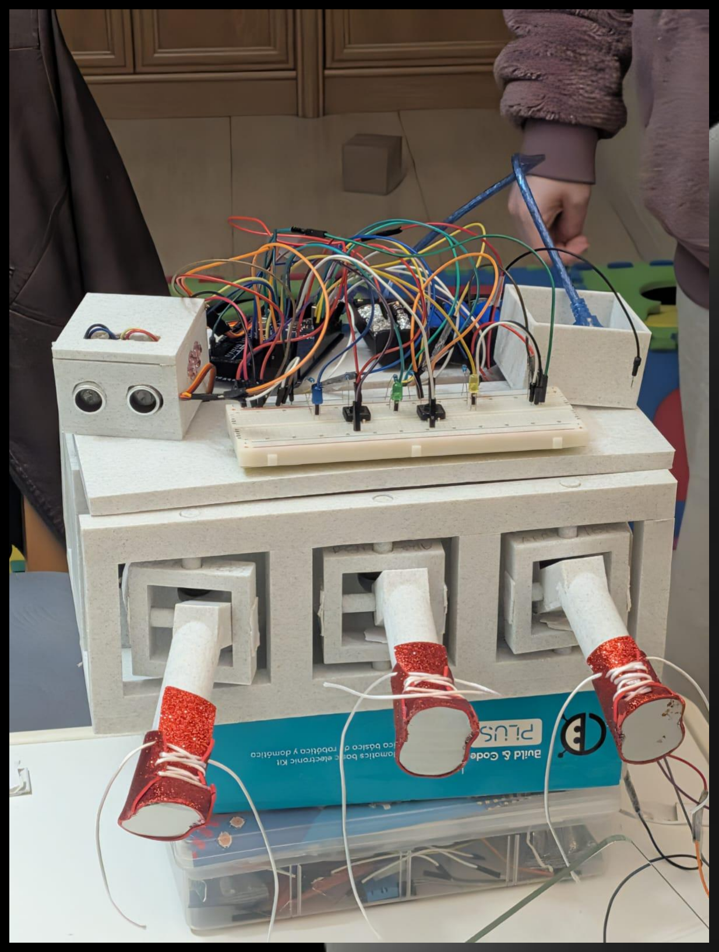
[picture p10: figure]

Componentes:
- 2 cabezas con un sensor de distancia y un servomotor de 180 grados
- 6 patas con 6 servomotores respectivamente
- 1 Tapa modular
- 1 caja de carga
- 2 Protoboards, una debajo de la tapa para los servos y otra por encima con los demás mecanismos
- Botones para los distintos programas
- LEDs para indicar los distintos estados

# Lluvia de ideas

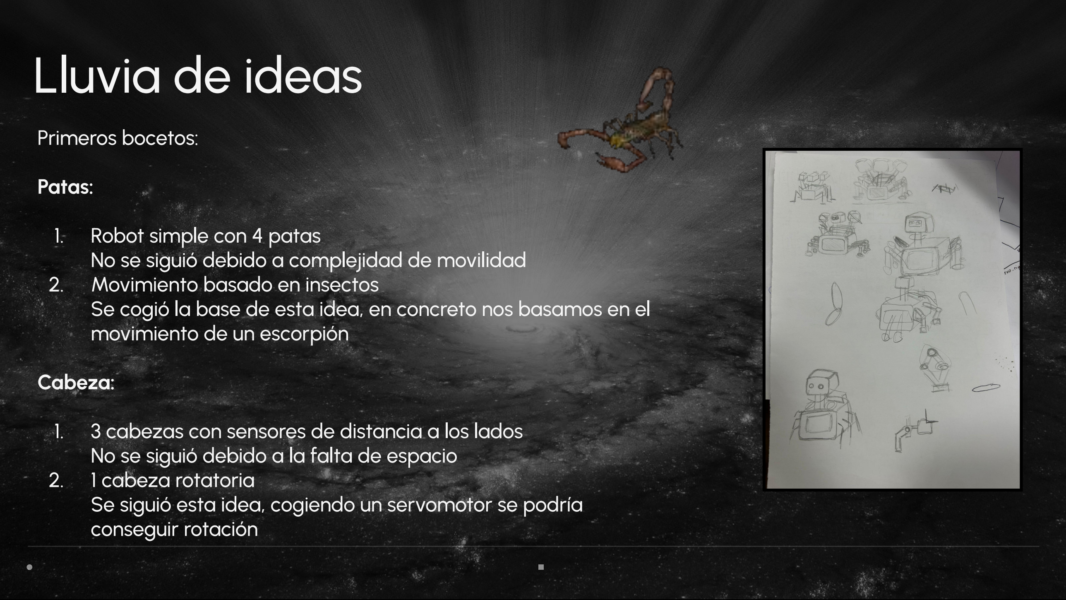
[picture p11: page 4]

Primeros bocetos:

Patas:

1. Robot simple con 4 patas
No se siguió debido a complejidad de movilidad
2. Movimiento basado en insectos
Se cogió la base de esta idea, en concreto nos basamos en el movimiento de un escorpión

Cabeza:

1. 3 cabezas con sensores de distancia a los lados
No se siguió debido a la falta de espacio
2. 1 cabeza rotatoria
Se siguió esta idea, cogiendo un servomotor se podría conseguir rotación

# Proceso

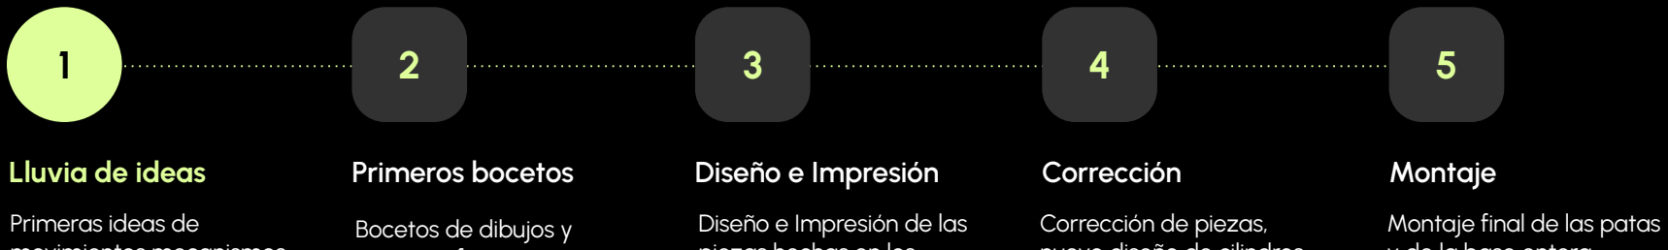
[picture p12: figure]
Lluvia de ideas; Primeros bocetos; Diseño e Impresión; Corrección; Montaje; Primeras ideas de; Bocetos de dibujos y; Diseño e Impresión de las; Corrección de piezas,; Montaje final de las patas

Octubre | Noviembre | Diciembre | Diciembre
Septiembre

movimientos mecanismos
y aspecto general.

primeras formas con
plastilina y otros
materiales

piezas hechas en los
bocetos con blender

nuevo diseño de cilindros
y patas

y de la base entera

# Problemas y

Soluciones | Comunicación
- No había unanimidad en la decisión del diseño
- Desacuerdo en los mecanismos
- Falta de entendimiento
- Comunicación dificultosa

1

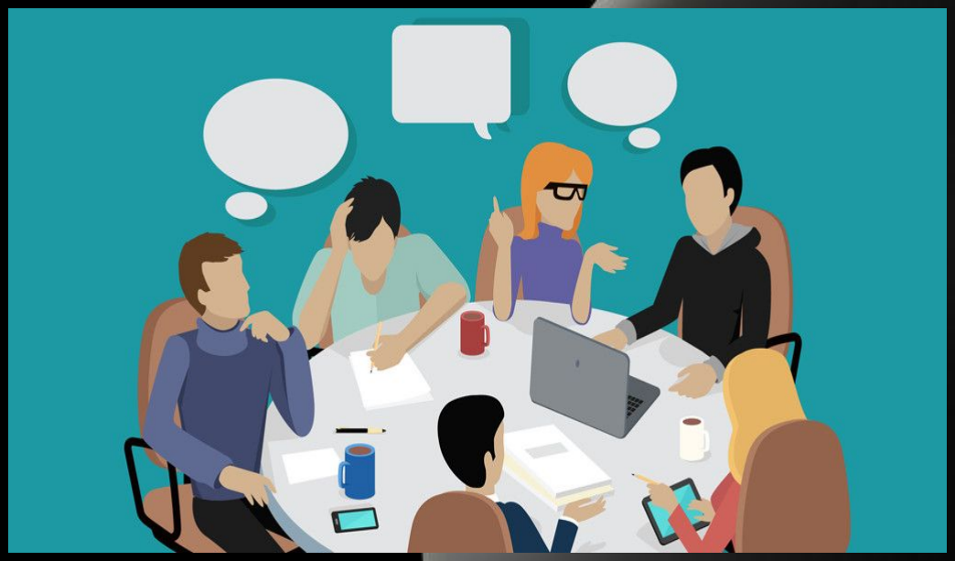
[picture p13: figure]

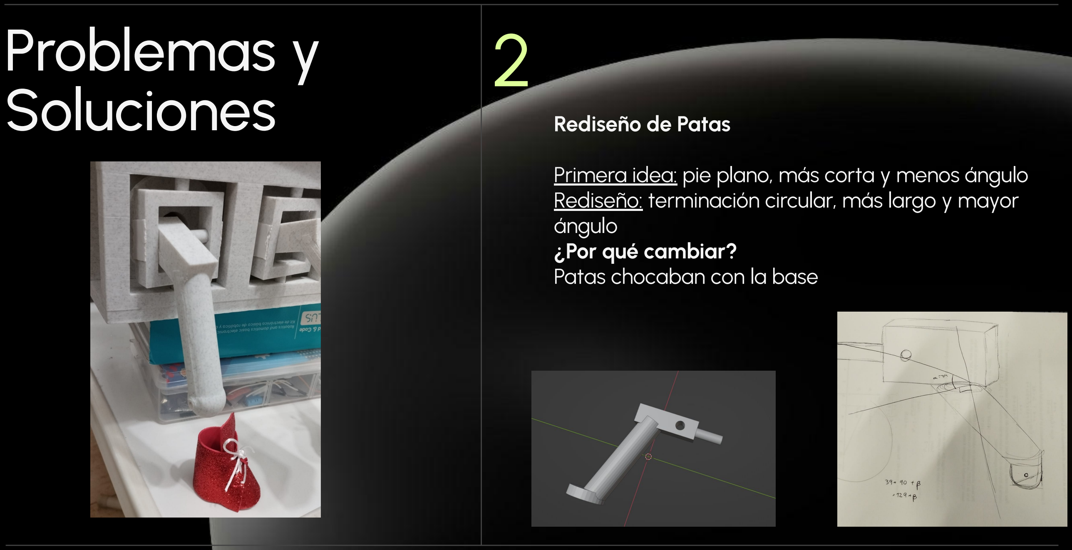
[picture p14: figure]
Problemas y; Soluciones; Rediseño de Patas; ángulo ¿Por qué cambiar? Patas chocaban con la base

Primera idea: pie plano, más corta y menos ángulo Rediseño: terminación circular, más largo y mayor

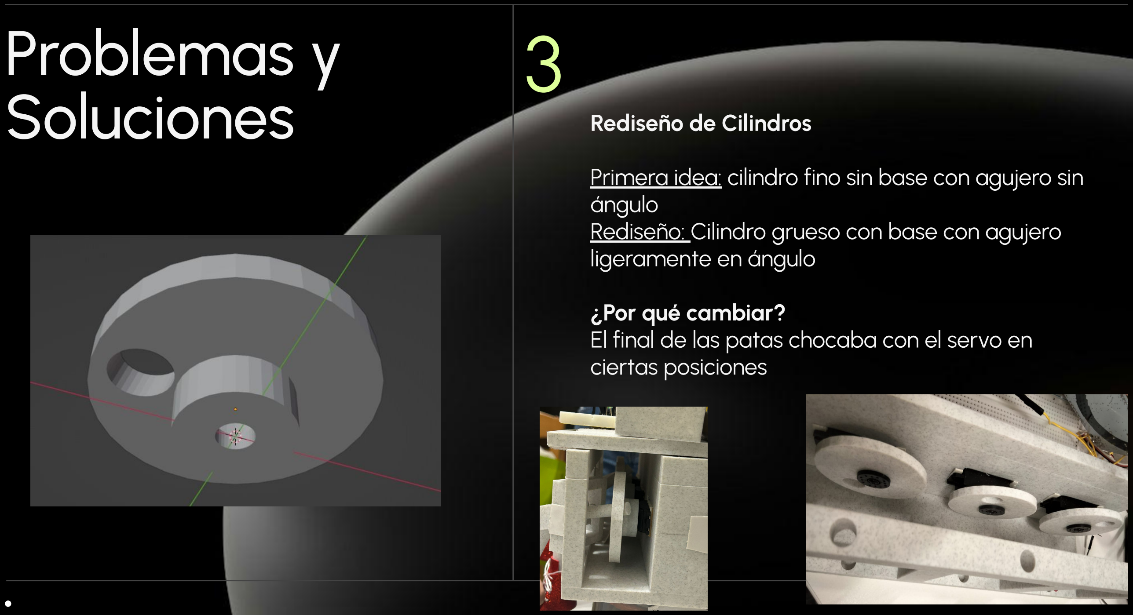
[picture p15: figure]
Problemas y; Soluciones; Rediseño de Cilindros; ángulo; ligeramente en ángulo; ¿Por qué cambiar?; ciertas posiciones

Primera idea: cilindro fino sin base con agujero sin

Rediseño: Cilindro grueso con base con agujero

El final de las patas chocaba con el servo en

# Problemas y

Soluciones | Modificación de la base

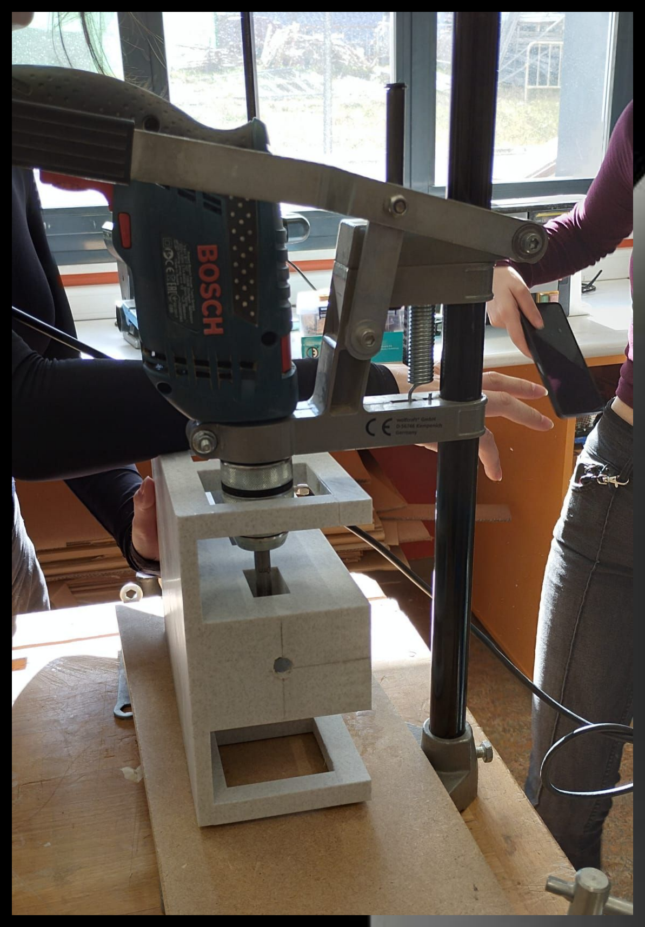
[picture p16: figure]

1. Falta de espacio para los cables de los
| servomotores
2. Alineación incorrecta de los servomotores
| con el mecanismo de las patas
3. Cabeza adicional por debajo
| ¿Qué hemos hecho? Taladrar agujeros en los sitios correspondientes y limar los recuadros de los motores añadiendo también topes

4

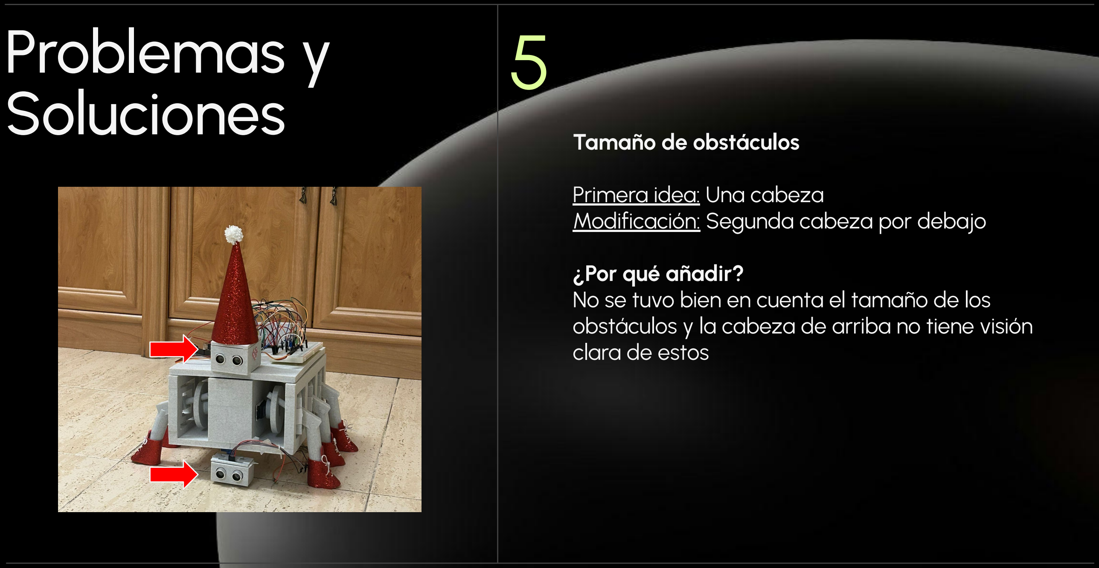
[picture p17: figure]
Problemas y; Soluciones; Tamaño de obstáculos; Primera idea: Una cabeza Modificación: Segunda cabeza por debajo; ¿Por qué añadir?; clara de estos

No se tuvo bien en cuenta el tamaño de los obstáculos y la cabeza de arriba no tiene visión

### Problema 1

# Problemas a Futuro

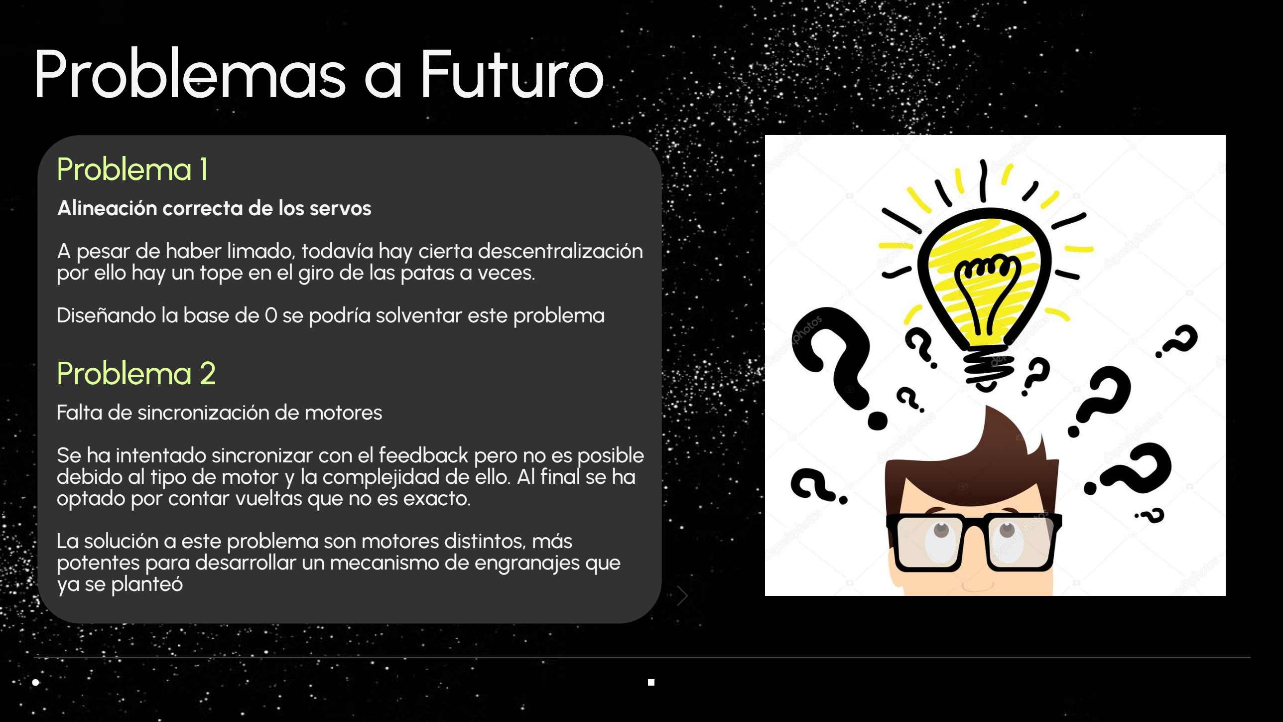
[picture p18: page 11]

Alineación correcta de los servos
A pesar de haber limado, todavía hay cierta descentralización por ello hay un tope en el giro de las patas a veces.
Diseñando la base de 0 se podría solventar este problema

### Problema 2

Falta de sincronización de motores
Se ha intentado sincronizar con el feedback pero no es posible debido al tipo de motor y la complejidad de ello. Al final se ha optado por contar vueltas que no es exacto.
La solución a este problema son motores distintos, más potentes para desarrollar un mecanismo de engranajes que ya se planteó

# Videos de Funcionamiento

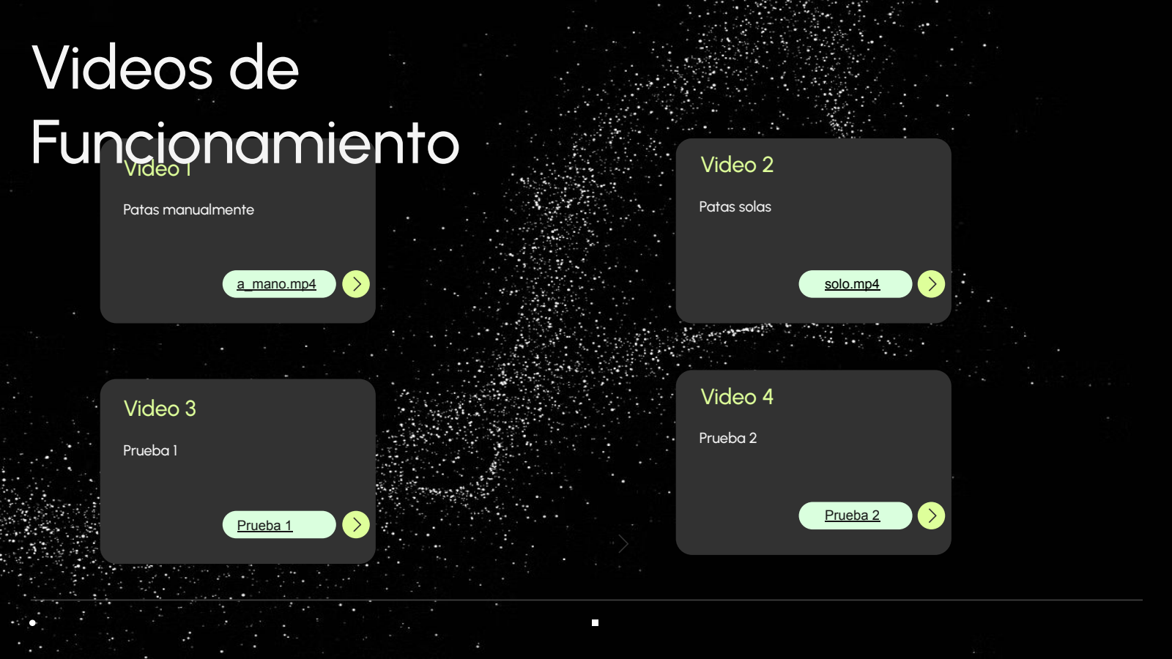
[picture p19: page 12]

Video 1

Patas manualmente

Video 2

Patas solas

a_mano.mp4 (https://urjc-my.sharepoint.com/personal/s_calvo_2022_alumnos_urjc_es/_layouts/15/stream.aspx?ga=1) | solo.mp4 (https://urjc-my.sharepoint.com/personal/s_calvo_2022_alumnos_urjc_es/_layouts/15/stream.aspx?ga=1)

Video 3

Prueba 1

Prueba 1 (https://urjc-my.sharepoint.com/:v:/g/personal/s_calvo_2022_alumnos_urjc_es/IQAR8DhPumfDQJ9OUBlGj9EbAV2BsdUYt-KR_YxpoAITlIY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)

Video 4

Prueba 2

Prueba 2 (https://urjc-my.sharepoint.com/:v:/g/personal/s_calvo_2022_alumnos_urjc_es/IQDzT4Fr9VQbTYZiGAz4xM3JAZHUH1uVe59XeowYf9VTlEc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)

# Conclusión

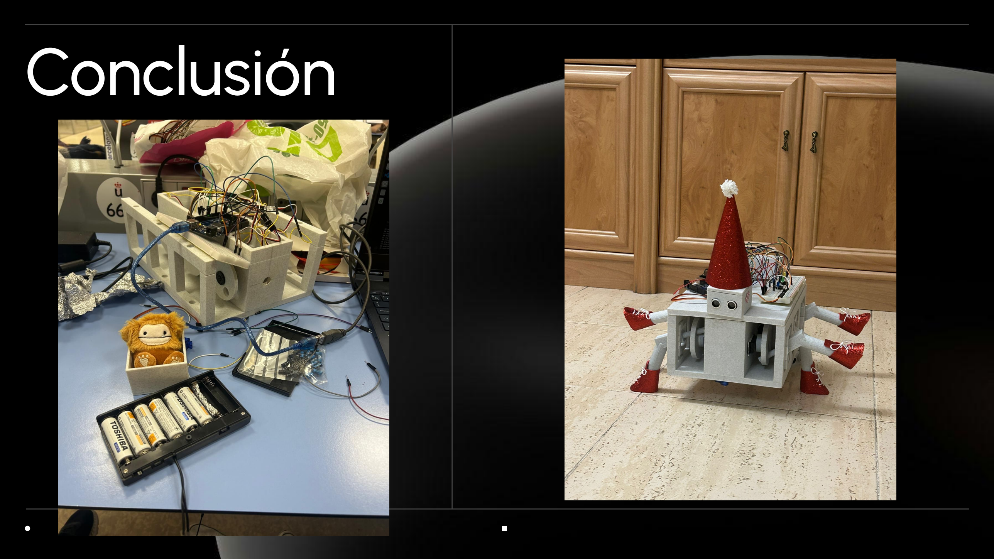
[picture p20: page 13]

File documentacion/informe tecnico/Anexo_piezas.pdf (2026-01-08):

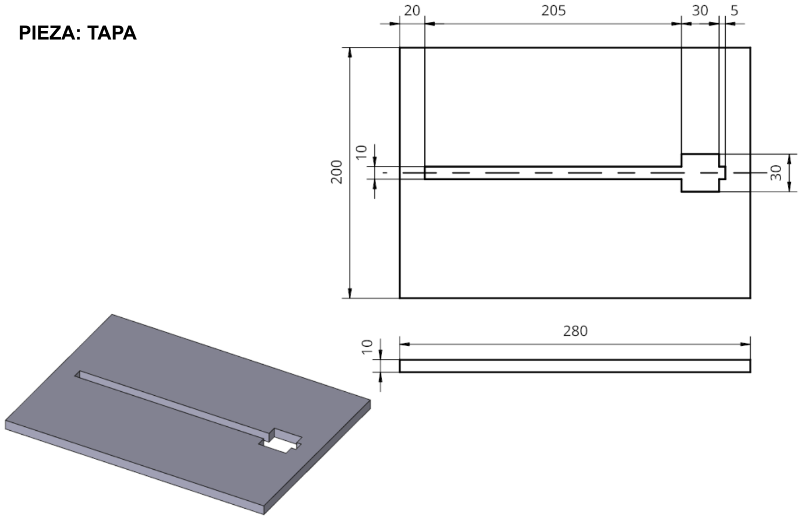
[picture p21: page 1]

PIEZA: TAPA

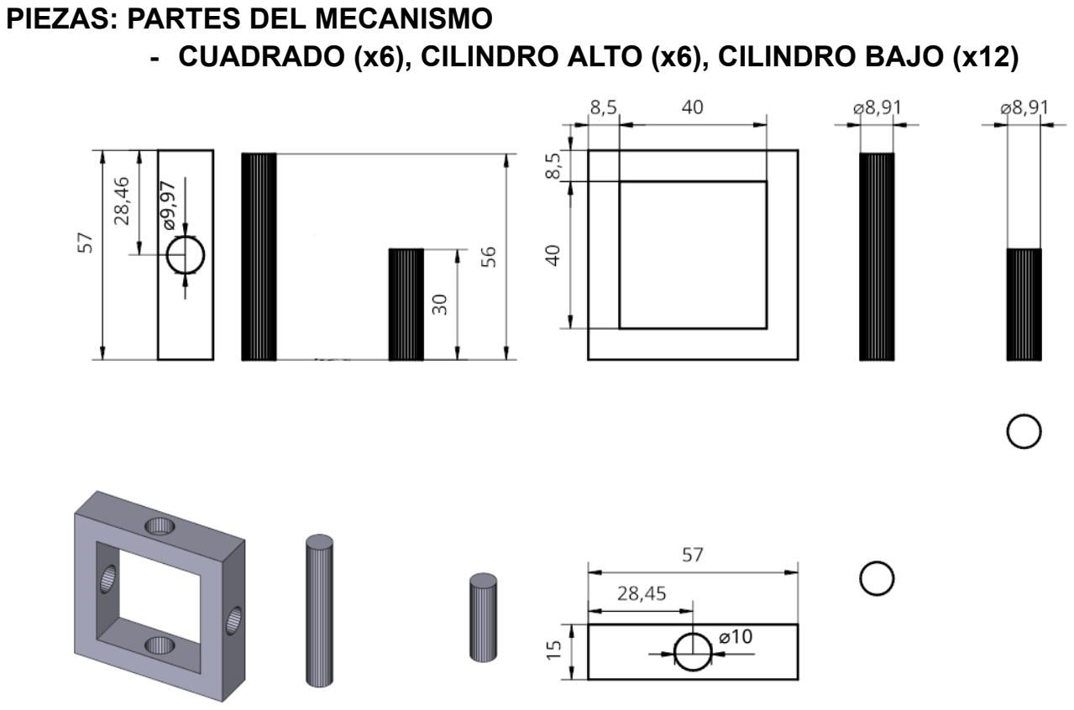
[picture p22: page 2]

PIEZAS: PARTES DEL MECANISMO
- CUADRADO (x6), CILINDRO ALTO (x6), CILINDRO BAJO (x12)

PIEZA: CAJA DE CARGA

PIEZA: CABEZA 1

PIEZA: TAPA CABEZA 1

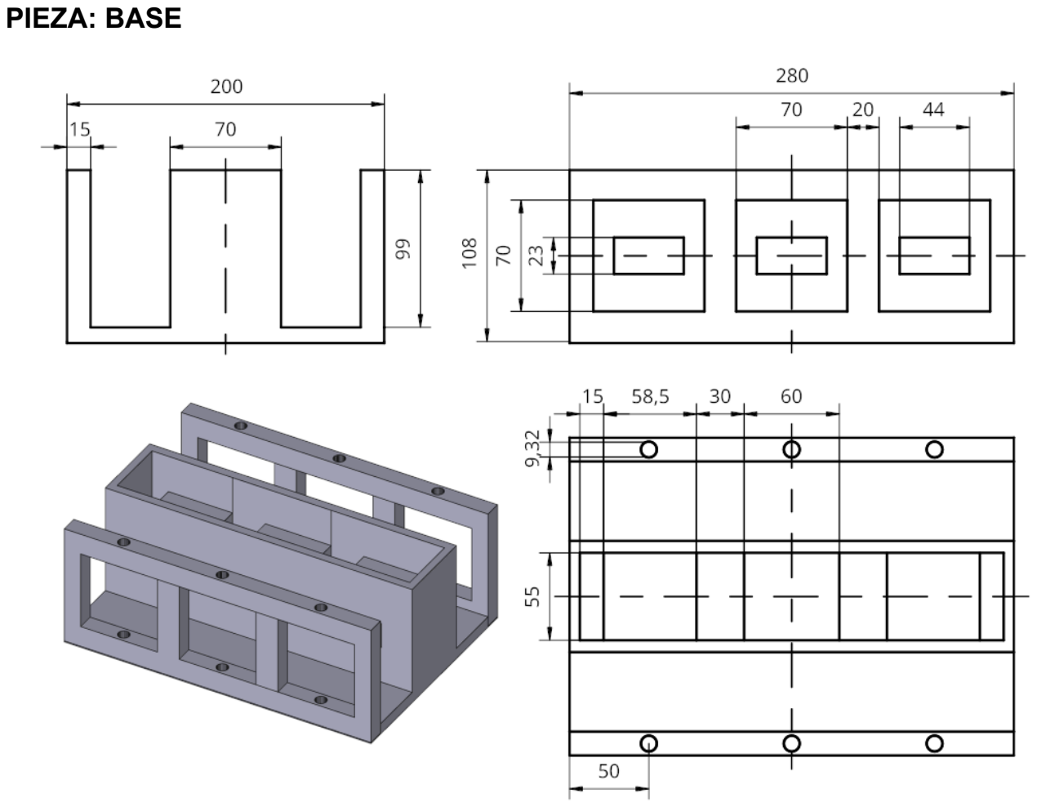
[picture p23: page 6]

PIEZA: BASE

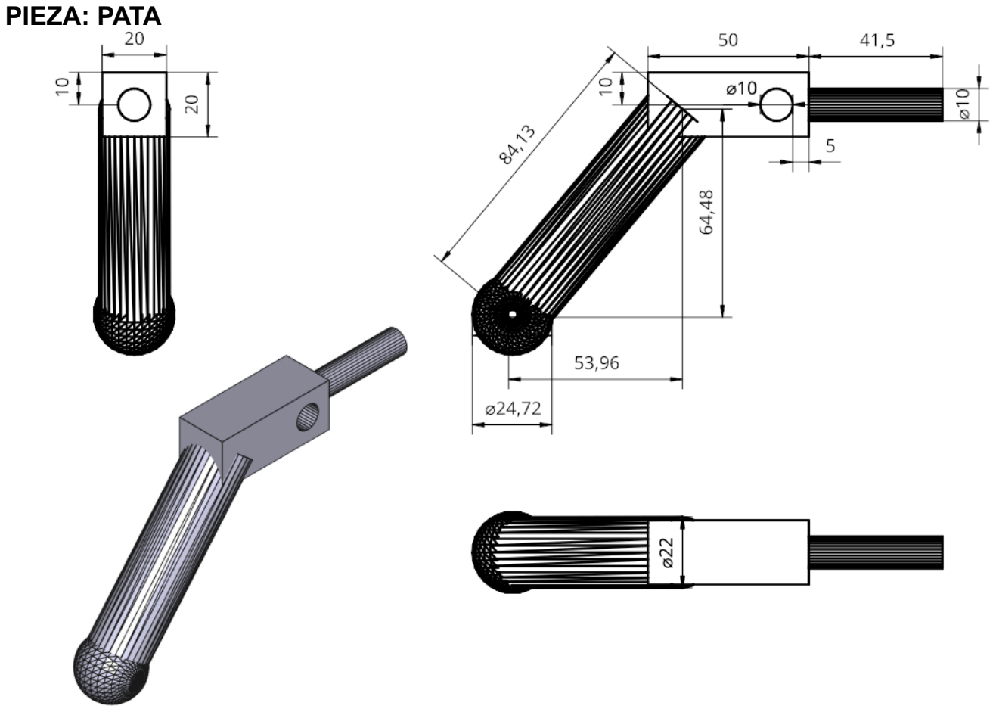
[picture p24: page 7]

PIEZA: PATA

PIEZA: ENGRANAJE


PIEZA: CABEZA 2

PIEZA: TAPA CABEZA 2

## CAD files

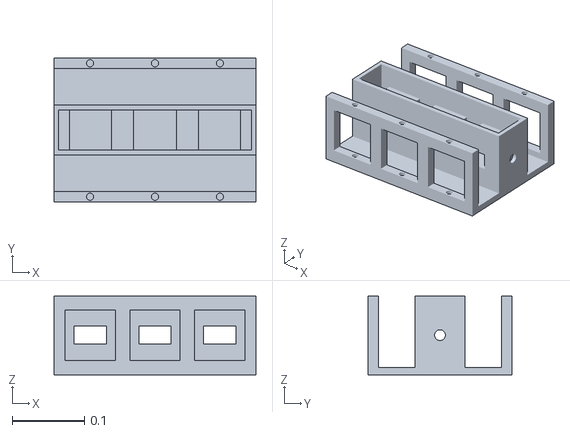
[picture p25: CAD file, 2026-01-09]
documentacion/piezas/piezas_stl/base_motores.stl
0.28 x 0.2 x 0.109

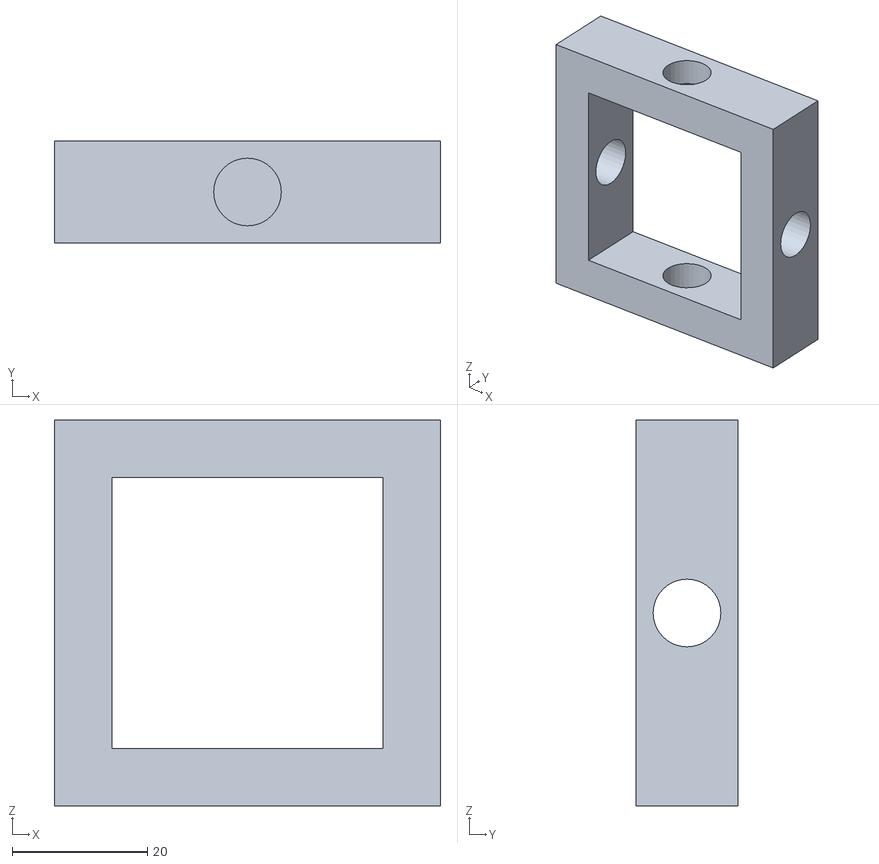
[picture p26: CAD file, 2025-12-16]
documentacion/piezas/piezas_stl/cuadrado.stl
57.0 x 15.0 x 57.0

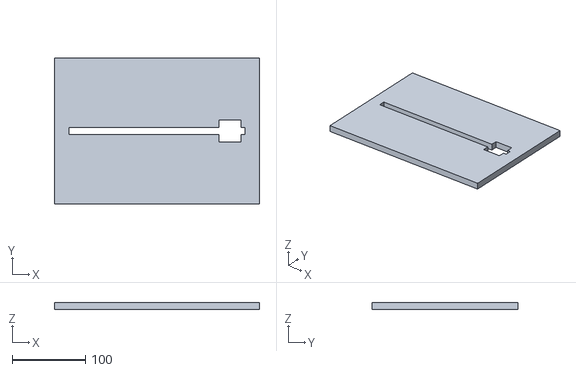
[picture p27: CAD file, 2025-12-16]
documentacion/piezas/piezas_stl/tapa.stl
280.0 x 200.0 x 10.0

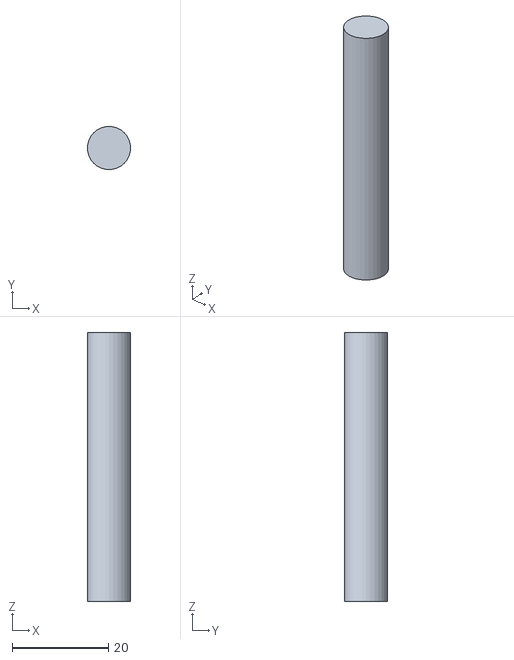
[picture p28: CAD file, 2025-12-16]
documentacion/piezas/piezas_stl/cilindro_largo.stl
9.00 x 9.00 x 56.0

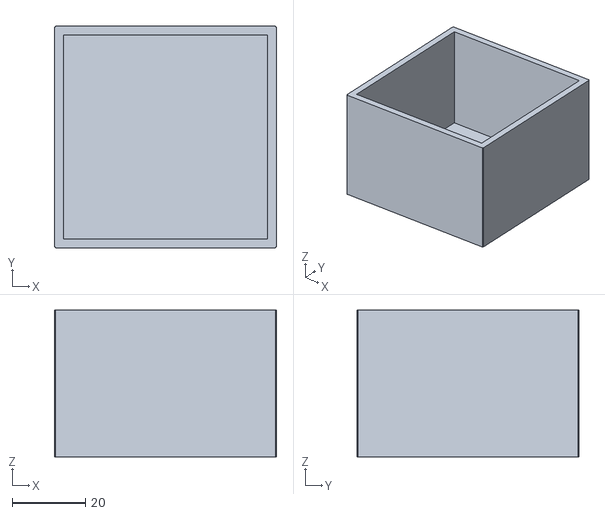
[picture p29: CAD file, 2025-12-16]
documentacion/piezas/piezas_stl/caja_carga.stl
60.5 x 60.5 x 40.0

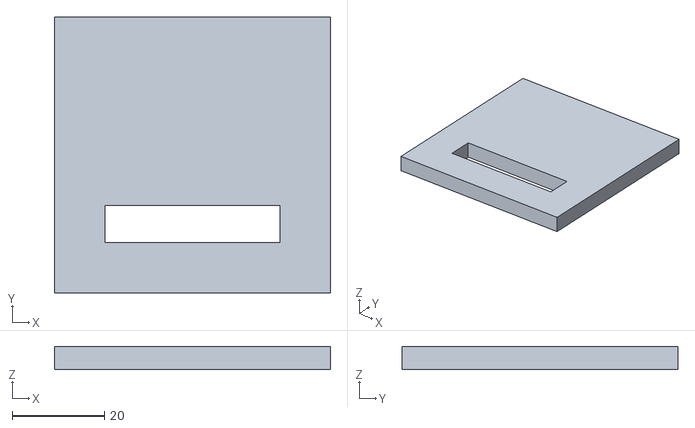
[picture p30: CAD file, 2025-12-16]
documentacion/piezas/piezas_stl/tapa_cabeza1.stl
60.0 x 60.0 x 5.00

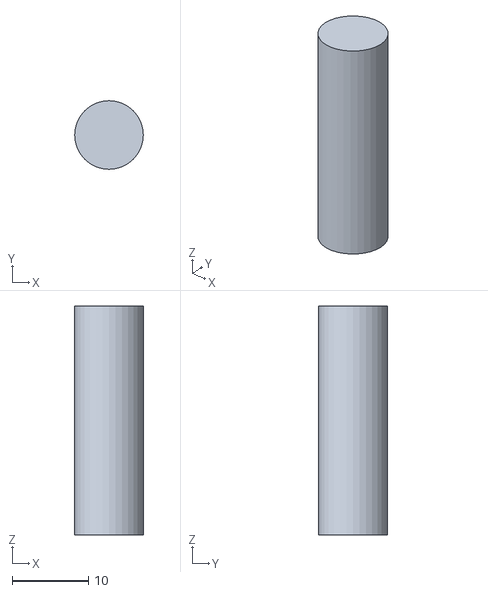
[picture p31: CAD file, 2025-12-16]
documentacion/piezas/piezas_stl/cilindro_corto.stl
9.00 x 9.00 x 30.0

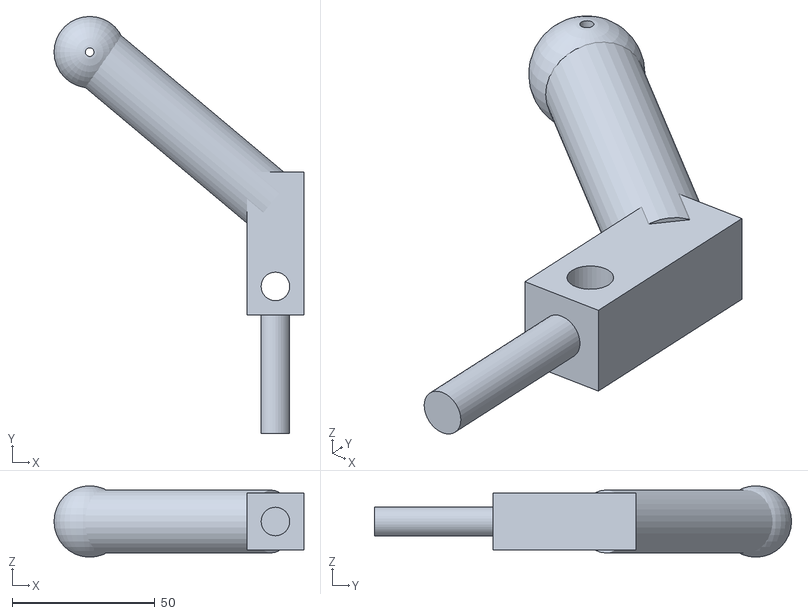
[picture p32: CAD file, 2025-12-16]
documentacion/piezas/piezas_stl/pata.stl
87.5 x 146.0 x 24.7

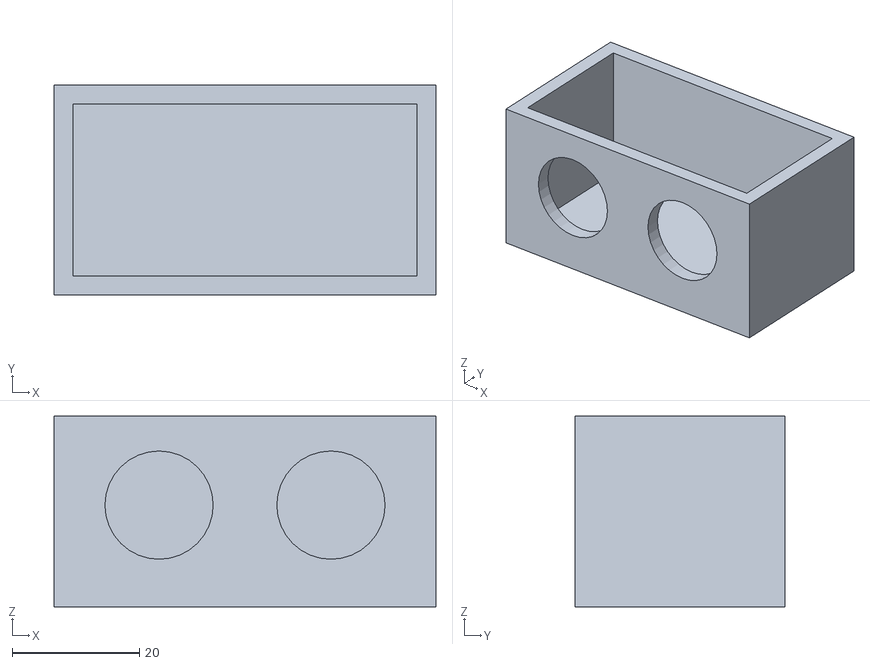
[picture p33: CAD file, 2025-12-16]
documentacion/piezas/piezas_stl/cabeza2.stl
60.0 x 33.0 x 30.0

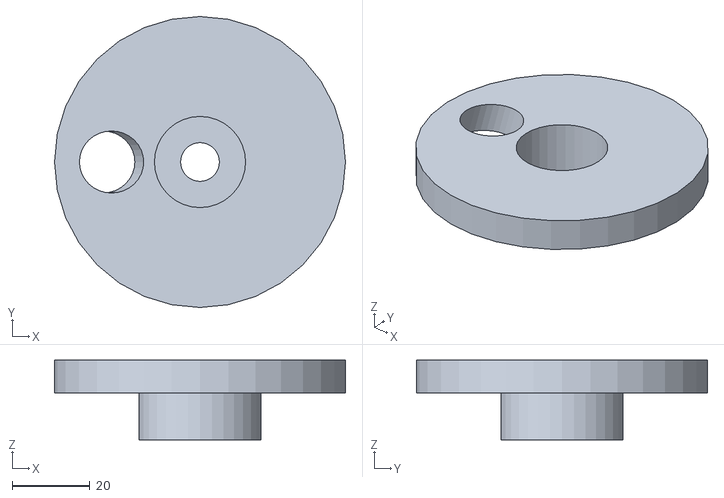
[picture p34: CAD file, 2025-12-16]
documentacion/piezas/piezas_stl/engranaje.stl
75.0 x 75.0 x 20.5

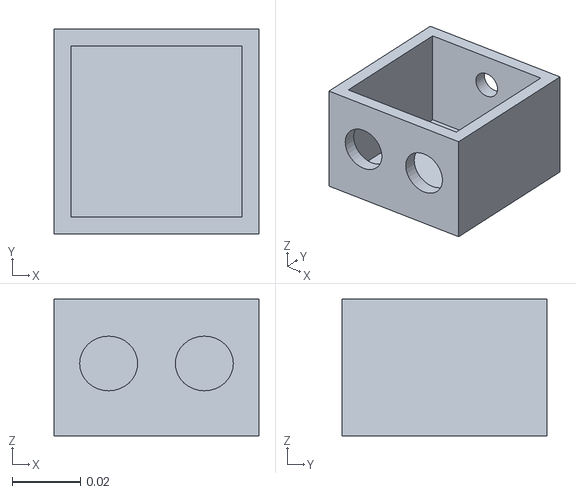
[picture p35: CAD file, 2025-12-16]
documentacion/piezas/piezas_stl/cabeza1.stl
0.06 x 0.06 x 0.04

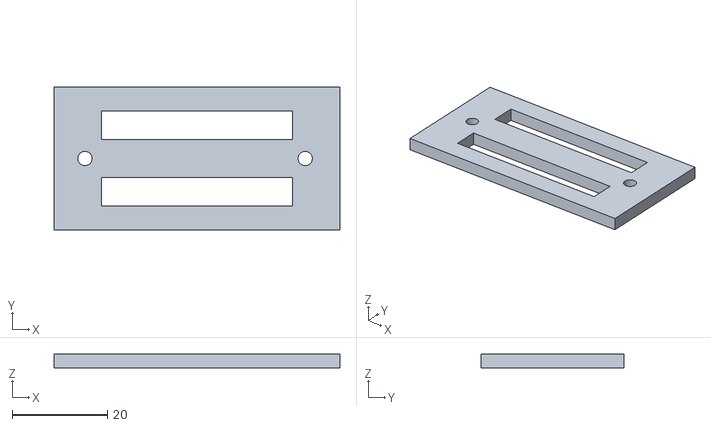
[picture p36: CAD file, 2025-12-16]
documentacion/piezas/piezas_stl/tapa_cabeza2.stl
60.0 x 30.0 x 3.00

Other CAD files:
documentacion/intento_simulacion/oroga_patucos.blend
documentacion/intento_simulacion/oruga.blend
documentacion/intento_simulacion/patucos_exp.blend
documentacion/intento_simulacion/patucos_simulacion.blend
documentacion/piezas/blender/base_motores.blend
documentacion/piezas/blender/cabeza1.blend
documentacion/piezas/blender/cabeza2.blend
documentacion/piezas/blender/caja_carga.blend
documentacion/piezas/blender/cilindro_corto.blend
documentacion/piezas/blender/cilindro_largo.blend
documentacion/piezas/blender/cuadrado.blend
documentacion/piezas/blender/engranaje.blend
documentacion/piezas/blender/pata.blend
documentacion/piezas/blender/tapa.blend
documentacion/piezas/blender/tapa_cabeza1.blend
documentacion/piezas/blender/tapa_cabeza2.blend

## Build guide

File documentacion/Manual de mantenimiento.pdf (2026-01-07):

# MANUAL DE MANTENIMIENTO

# PATUQUITO

# Mecatrónica

## IRENE DIEZ DE TORO

## SANDRA GONZALEZ ALONSO

VALERIA STOBINSKI ADILLO (https://www.aulavirtual.urjc.es/moodle/user/view.php?id=244258&course=237750)

## SILVIA CALVO CABELLO

## 4º INGENIERÍA ROBÓTICA SOFTWARE

12-12-2025


# Indice

# Introducción

Este manual de mantenimiento tiene como objetivo proporcionar al usuario toda la información necesaria para asegurar el correcto funcionamiento, la seguridad operativa y la máxima durabilidad del hexápodo modular. A lo largo de este documento se describen en detalle los procedimientos de inspección, limpieza, ajustes rutinarios y cuidados preventivos que deben realizarse de manera periódica para evitar fallos prematuros y garantizar un rendimiento óptimo del sistema.

El manual está diseñado tanto para usuarios con conocimientos básicos como para personal técnico encargado del mantenimiento. Aquí se incluyen instrucciones claras, recomendaciones prácticas y pautas de actuación ante situaciones comunes que pueden surgir durante el uso del robot. Asimismo, se ofrecen indicaciones para la detección temprana de anomalías y el manejo adecuado del equipo en función de sus características y limitaciones.

Siguiendo cuidadosamente las directrices expuestas, el usuario podrá mantener el robot en condiciones óptimas de operación, preservando la integridad de sus componentes, reduciendo la necesidad de reparaciones mayores y asegurando que el sistema continúe funcionando conforme a las especificaciones del diseño original. Este manual debe considerarse una referencia fundamental para cualquier intervención relacionada con el mantenimiento del robot.

## Frecuencia de mantenimiento recomendada

La frecuencia de mantenimiento recomendada para el robot se establece para garantizar un funcionamiento fiable y prolongar la vida útil de sus componentes.
En primera instancia, revise los engranajes antes de cada uso. Se aconseja realizar una revisión ligera cada dos o tres semanas, comprobando el estado general del robot, limpiando superficialmente las superficies accesibles y verificando que no existan daños visibles ni elementos sueltos.
Cada dos o tres meses debe realizarse un mantenimiento más detallado, revisando uniones, sensores, conectores y estado del sistema eléctrico, así como limpiando con mayor profundidad las zonas móviles.
De forma semestral, se recomienda comprobar el desgaste de las partes sometidas a fricción y verificar que el software mantiene sus parámetros originales.
Finalmente, una vez cada 5 años debe efectuarse una inspección completa por personal técnico cualificado, reemplazando componentes críticos y confirmando el funcionamiento integral del sistema.
Cumplir estos intervalos reduce el riesgo de averías y garantiza un rendimiento estable y seguro del hexápodo modular..

# Mantenimiento preventivo

Limpieza de componentes mecánicos y eléctricos.

La limpieza de los componentes mecánicos y electrónicos del robot es una tarea fundamental para garantizar su funcionamiento seguro, estable y prolongado en el tiempo. Dado que estos elementos son especialmente sensibles al polvo, humedad y manipulación inadecuada, el proceso debe realizarse siguiendo pautas específicas y empleando únicamente instrumentos apropiados.

Los componentes electrónicos (como la placa Arduino, la protoboard, los sensores, cables y conectores) deben limpiarse utilizando aire comprimido, pinceles antiestáticos o paños de microfibra secos. Los sensores deben mantenerse limpios para asegurar mediciones precisas. En estos casos, es conveniente limpiar la superficie frontal con un paño suave sin aplicar presión excesiva. Cualquier mancha, huella o partícula puede interferir en la lectura, por lo que se debe realizar esta limpieza con especial atención. Es importante evitar completamente el uso de líquidos o aerosoles que puedan penetrar en los circuitos, ya que podrían causar cortocircuitos o corrosión. Durante la limpieza, debe desconectar la alimentación del robot y manipular las piezas únicamente por los bordes para evitar descargas electrostáticas o daño a los contactos.

En cuanto a los componentes mecánicos, como motores, soportes, engranajes o ejes móviles, la limpieza debe centrarse en eliminar partículas de polvo, restos de suciedad o acumulaciones que puedan dificultar el movimiento. Para ello es suficiente un cepillo de cerdas suaves o un paño ligeramente humedecido (sólo en superficies externas y nunca en partes eléctricas o internas del motor). No se recomienda abrir los motores ni lubricarlos sin la supervisión de personal cualificado, ya que podría afectar al funcionamiento interno o comprometer la calibración original del sistema.

## Revisión de servomotores y articulaciones

La revisión periódica de los servomotores y articulaciones del robot es esencial para garantizar un movimiento fluido, preciso y seguro. Estos componentes están sometidos a esfuerzos mecánicos constantes y pueden presentar desgaste, pérdida de par o desviaciones en su posición con el tiempo si no se supervisan adecuadamente.

La inspección debe comenzar verificando que los servomotores esten posicionados de manera correcta con respecto al sentido del giro. Antes de montarlos se recomienda engrasar estos mismos. Verificar que funcionen dentro de los parámetros establecidos, comprobando que respondan correctamente a las órdenes y que no presenten vibraciones, movimientos bruscos o ruidos anómalos. Es recomendable realizar pequeñas pruebas de desplazamiento y observar la suavidad del recorrido, así como asegurarse de que alcanzan los ángulos programados sin retrasos ni bloqueos. También debe revisarse la temperatura de los servos tras un periodo breve de funcionamiento: un sobrecalentamiento puede indicar un exceso de carga, fricción en la articulación o una configuración inadecuada en el sistema.

En las articulaciones, es importante inspeccionar la firmeza de los tornillos, engranajes y uniones mecánicas. Cualquier holgura, desalineación o dureza en el movimiento puede afectar significativamente al rendimiento del robot. No debe aplicarse lubricante salvo que el diseño lo requiera expresamente, ya que podría atraer suciedad o afectar negativamente a los componentes cercanos.

## Comprobación de cables y conectores

La comprobación periódica de cables y conectores es fundamental para asegurar la integridad eléctrica del robot y prevenir fallos en la comunicación o alimentación de los componentes. Los cables deben revisarse visualmente para detectar cortes, peladuras, desgastes, dobleces excesivos o signos de sobrecalentamiento. Se debe comprobar que la funda aislante esté intacta, que no haya puntos donde los hilos internos queden expuestos, ya que esto puede generar cortocircuitos o pérdidas de señal, y que no esten en tensión. En caso de querer retirar los servomotores, no tire de los cables.

Los conectores, tanto hembra como macho, deben inspeccionarse para garantizar que encajan correctamente y mantienen un contacto firme. Debe prestarse especial atención a pines doblados o sucios, terminales flojos y señales de corrosión, ya que pueden afectar directamente al funcionamiento del sistema.

Durante la revisión, se recomienda también verificar que los cables estén correctamente organizados y sujetos, evitando tensiones excesivas, cruces innecesarios o puntos de roce con partes móviles. Esto reduce el riesgo de rotura o desconexión accidental durante la operación.

## Carga y estado de la batería

El correcto manejo y monitoreo de la batería del robot es crucial para garantizar un funcionamiento seguro, prolongar su vida útil y evitar fallos durante la operación. Se recomienda cargar la batería únicamente con el cargador proporcionado, siguiendo las especificaciones de voltaje y corriente indicadas en el manual de usuario..

Antes de cada uso o de manera periódica, verifique el estado de la batería observando indicadores de carga, nivel de voltaje y posibles signos de deterioro, como hinchazón, fugas, sobrecalentamiento o corrosión en los terminales. Nunca se debe utilizar una batería que presente daños físicos o señales de desgaste avanzado, ya que esto puede generar riesgos de cortocircuito, incendio o mal funcionamiento del robot.

Evite cargar la batería a temperaturas extremas, ya que esto puede afectar su capacidad y vida útil. Se recomienda no dejar la batería conectada de manera prolongada innecesariamente.

Por último, para mantener un rendimiento óptimo, se aconseja realizar ciclos completos de carga y descarga de forma periódica, evitando descargas profundas frecuentes que puedan degradar la batería.

# Mantenimiento correctivo

El mantenimiento correctivo comprende todas las intervenciones realizadas tras la detección de un fallo, desgaste o comportamiento anómalo del robot. Su objetivo es restaurar el funcionamiento normal del sistema de forma segura, precisa y con el menor impacto posible en la integridad del equipo. Las acciones descritas a continuación deben ser realizadas por personal cualificado y siguiendo las normas de seguridad establecidas para el robot.

## Sustitución de servomotores dañados

La sustitución de servomotores es necesaria cuando se detectan señales de fallo como pérdida de torque, vibraciones anómalas, ruido excesivo, sobrecalentamiento o falta de respuesta ante las órdenes del controlador.
Procedimiento:
1. Desconectar el robot de la alimentación principal.
2. Identificar el servomotor averiado mediante diagnóstico con el controlador o inspección física.
3. Desconectar el cableado y etiquetarlo para evitar conexiones erróneas.
4. Retirar con precaución las sujeciones que fijan el servomotor a la estructura. Para retirar este, no tire de los cables.
5. Instalar el nuevo servomotor asegurando la correcta alineación mecánica y fijación..
6. Reconectar el cableado y comprobar la polaridad y continuidad.
7. Ejecutar el código de prueba para comprobar su correcto funcionamiento.

## Reemplazo de piezas estructurales

Las piezas estructurales pueden requerir cambio por deformaciones, fracturas, desgaste excesivo o compromisos en la rigidez del robot. En caso de, tras una inspección visual y mecánicamente del hexápodo modular, encontrar una pieza defectuosa/quebrada; proceda a contactar con nuestro soporte. Se le enviará un repuesto de dicha pieza.
Para poder proceder con el cambio deberá:
1. Desmontar los componentes adyacentes que impidan el acceso.
2. Retirar la pieza dañada respetando el orden original de montaje.
3. Instalar la nueva pieza verificando tolerancias y ajustes mecánicos.
4. Reensamblar el resto de componentes y realizar pruebas de integridad estructural y alineación.

## Reprogramación del Arduino

Cuando el controlador presenta fallos de ejecución, comportamiento inesperado o se necesita actualizar funcionalidades, puede ser necesaria la reprogramación del Arduino. Por ello, en caso de experimentar esto, conecte el USB del Arduino a su dispositivo más cercano para poder descargar de nuevo (o la nueva versión) el código funcional del hexápodo modular publicado en el repositorio de Github oficial del soporte técnico.

## Verificación de sensores

Los sensores deben ser revisados cuando existen incoherencias en las lecturas, falta de actualización, ruido inusual en los datos o fallos de comunicación. Para ello, debe fijarse en el comportamiento del hexápodo modular. Si tras comprobar que físicamente está todo correcto y el código actualizado, puede estar relacionado con este apartado. Si experimenta alguno de estos casos, siga las instrucciones y contacte con nuestro soporte para un reemplazo del sensor, dentro de la garantía establecida.

Procedimiento:

1. Comprobar las conexiones eléctricas y el estado físico del sensor.
2. Revisar la alimentación y el nivel de tensión recibida.
3. Realizar pruebas individuales mediante herramientas de diagnóstico (serial monitor, scripts de prueba, etc.).
4. Verificar la calibración y aplicarla nuevamente si es necesario.
5. Sustituir el sensor si se detecta fallo irrecuperable. Proceda con el desmontaje de piezas que obstaculicen su retirada.
6. Confirmar la correcta lectura desde el sistema principal del robot.

# Calibración del sistema

La calibración del sistema es un proceso esencial para asegurar que el robot mantenga una postura estable, movimientos precisos y una coordinación adecuada entre sus patas y servomotores. Este procedimiento debe realizarse después del montaje inicial, tras cualquier reparación mecánica o electrónica y cada vez que se detecten desviaciones en la posición o comportamiento del robot.

## Ajuste de posición inicial de las patas

El ajuste de la posición inicial establece la referencia mecánica fundamental desde la cual el robot calcula y ejecuta todos sus movimientos. Durante esta fase se deben de posicionar manualmente las patas en su ángulo neutro: hacia abajo (delantera derecha, trasera derecha e izquierda central) y hacia arriba (delantera izquierda, trasera izquierda y derecha central), asegurándose de que las articulaciones no presenten torsiones o esfuerzos que puedan traducirse en lecturas incorrectas. Una vez fijada la postura base, los servomotores se deben de encender para verificar que son capaces de mantener la posición sin realizar microcorrecciones excesivas. Esta postura inicial sirve como punto de partida para todos los cálculos cinemáticos, por lo que cualquier desalineación afecta directamente a la estabilidad y simetría del desplazamiento.

## Sincronización de servos

La sincronización precisa de los servomotores garantiza que todas las articulaciones respondan de manera simultánea y coherente a las instrucciones del controlador. Para el movimiento fluido de un robot hexápodo, es imperativo mantener una precisión continua en la coordinación de sus patas.

Gestión de Anomalías y Ajustes

En caso de observar retrasos, vibraciones o comportamientos irregulares durante la operación, se deben seguir estos protocolos:

- Corrección de desviaciones: Si se detectan diferencias angulares entre servos que deberían compartir la misma posición, es necesario reajustar los offsets individuales de cada motor.
- Búsqueda de Simetría: El objetivo es lograr un movimiento completamente simétrico que distribuya las cargas de manera uniforme.
- Consecuencias de una Descalibración: Una sincronización deficiente puede derivar en:
- Inestabilidad estructural: El robot pierde su centro de gravedad.
- Cojera: Movimientos asíncronos que afectan la tracción.
- Trayectorias inconsistentes: Desviaciones respecto al rumbo programado.

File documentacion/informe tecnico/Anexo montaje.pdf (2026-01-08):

# Montaje

## Introducción al montaje

En este apartado se describen los pasos necesarios para el montaje correcto del robot. Es fundamental seguir las instrucciones cuidadosamente para garantizar un funcionamiento óptimo y seguro del dispositivo. Cada componente debe colocarse y fijarse correctamente, ya que cualquier error puede afectar la estabilidad y el desempeño del robot.

Este manual está diseñado para guiarle paso a paso, proporcionando instrucciones claras, recomendaciones de seguridad y consejos prácticos que faciliten el montaje incluso si es la primera vez que trabaja con este tipo de dispositivos. Al finalizar el montaje de todas las partes, el robot estará listo para la integración de los sistemas electrónicos y de control.

## Montaje de las patas

Introducción al montaje de una pata

Cada pata del robot es un componente fundamental que contribuye al movimiento, estabilidad y funcionalidad general del dispositivo. Por ello, es muy importante seguir cuidadosamente cada paso, asegurándose de que todos los elementos queden correctamente colocados y firmemente fijados.

Aunque en esta sección se describe únicamente el montaje de una pata, el procedimiento debe repetirse de manera idéntica para las seis patas del robot. Prestar atención a la orientación de los motores, la alineación de la base y la correcta fijación de cada componente garantizará que el robot funcione de manera estable y eficiente.

Pasos para montar una pata

Materiales necesarios:

- 1 Base (20 * 28 * 11 cm)
- 1 Tapa (20 * 28 * 1 cm)
- 6 Motores (cilindros de motor, radio 6 cm)
- 6 Patas
- 6 Cuadrados de patas (6 * 6 * 1.5 cm)
- 6 Cilindros traveseros para pata (6 cm de largo)
- 12 Cilindros mecanismo (3 cm de largo)

- 6 Cilindros motores ( 7.5 cm de radio)

Paso 1: Colocar los Motores

1. Tome los 6 motores y coloquelos en sus respectivos huecos en la base, asegurándose de que todos estén orientados en la misma dirección.
2. Saque los cables de los motores por el centro de la base para facilitar su conexión posterior.
3. A continuación, fije los motores a la base. Puede hacerlo aplicando pegamento resistente, silicona, cinta adhesiva de alta adherencia. Es importante que queden correctamente alineados y firmemente sujetos para evitar movimientos durante su funcionamiento

Paso 2: Montar los Cilindros de los motores

1. Desatornille el engranaje de los motores para poder colocar el cilindro entre el motor y el engranaje.
2. Coloque el cilindro de los motores entre el motor y el engranaje, asegurándose de que encaje correctamente.
3. Vuelva a atornillar el engranaje en su lugar, teniendo cuidado de no apretarlo en exceso ni dejarlo demasiado flojo. El tornillo debe quedar ajustado para evitar movimientos indeseados, pero sin dañar las piezas.

Paso 3: Montar el Cuadrado de la Pata

1. Tome un cuadrado de pata, una pata y un cilindro travesero.
2. Introduzca la pata dentro del cuadrado, asegurándose de que el agujero con tope en el cuadrado quede en la parte superior.
3. Alinee el hueco del cuadrado con el hueco correspondiente de la pata.
4. Inserte el cilindro travesero atravesando ambos, el cuadrado y la pata, de modo que queden firmemente unidos.
5. Fije el cilindro a los lados del cuadrado utilizando adhesivo o el método de fijación correspondiente, para evitar que se deslice o salga.

Paso 4: Colocar el Cilindro del Mecanismo

1. Coloque un cilindro mecanismo en la parte inferior del cuadrado de la pata.

2. Introduzca el cilindro en el hueco inferior del cuadrado de la base.
3. A continuación, coloque el cilindro superior del cuadrado en la parte superior y fíjelo en su lugar para asegurar que el mecanismo quede firme.
4. Verifique que el cilindro del mecanismo quede bien insertado y fijado al cuadrado de la pata.

Paso 5: Repetir el Proceso

Una vez montada la primera pata, repita este proceso para las otras cinco patas. Cuando haya terminado, su robot tendrá todas las patas montadas correctamente.

Pasos para montar el resto del robot:

Paso 1: Tapa modular

Este robot está pensado para que pueda colocar los componentes en distintas configuraciones según lo desee, para ello seleccione cuál va a ser la parte de arriba de la tapa, es necesario que coloque el velcro en la tapa creando varias filas a ambos lados de la rendija para pasar cables, a su vez coloque la otra parte del velcro en la parte inferior de los módulos, de las baterías, de la protoboard, la carga de pago, el arduino y cualquier otro módulo que desee crear.

Paso 2: Colocar el Ultrasonido en el hueco de la Cabeza

Para montar la cabeza, debe de observar que esta posee dos agujeros en una de las caras. Aquí deberá de meter y encajar el sensor ultrasonido.

Paso 3: Introducir los Cables en la Cabeza

Posteriormente, deberá de meter los cables que conectan al ultrasonido con el arduino en el agujero existente en la cara opuesta a la del sensor. Una vez pasados, debe de enchufarlos a las clavijas del sensor según corresponda.

Paso 4: Acomodar los Cables y Tapar la Cabeza

Tape y fije a la cabeza su tapa incorporada acomodando los cables por el agujero rectangular para simular estéticamente unas orejas. Por último, en la parte inferior de la cabeza fije de la forma que vea más conveniente la pieza blanca que se encaja en el servomotor.

Paso 5: Cabeza a Tapa
Fije en el hueco grande de la tapa el servomotor correspondiente al movimiento de la cabeza. Inserte la pieza blanca pegada en la cabeza en el servomotor (previamente instalado) de la tapa.

Paso 6: Tapa a base

Una vez estén montados los servomotores, los engranajes y las patas, y la cabeza; encaje la tapa modular encima del chasis. Esta viene incorporada con un velcro que la sujetará.

Paso 7: Repita los pasos anteriores para la cabeza inferior
Recuerde colocar bien los cables para que no se enreden con ninguna pata.

¡Enhorabuena! Ahora ha montado correctamente su robot

Pasos para montar una pata

Paso 1: Colocar los Motores

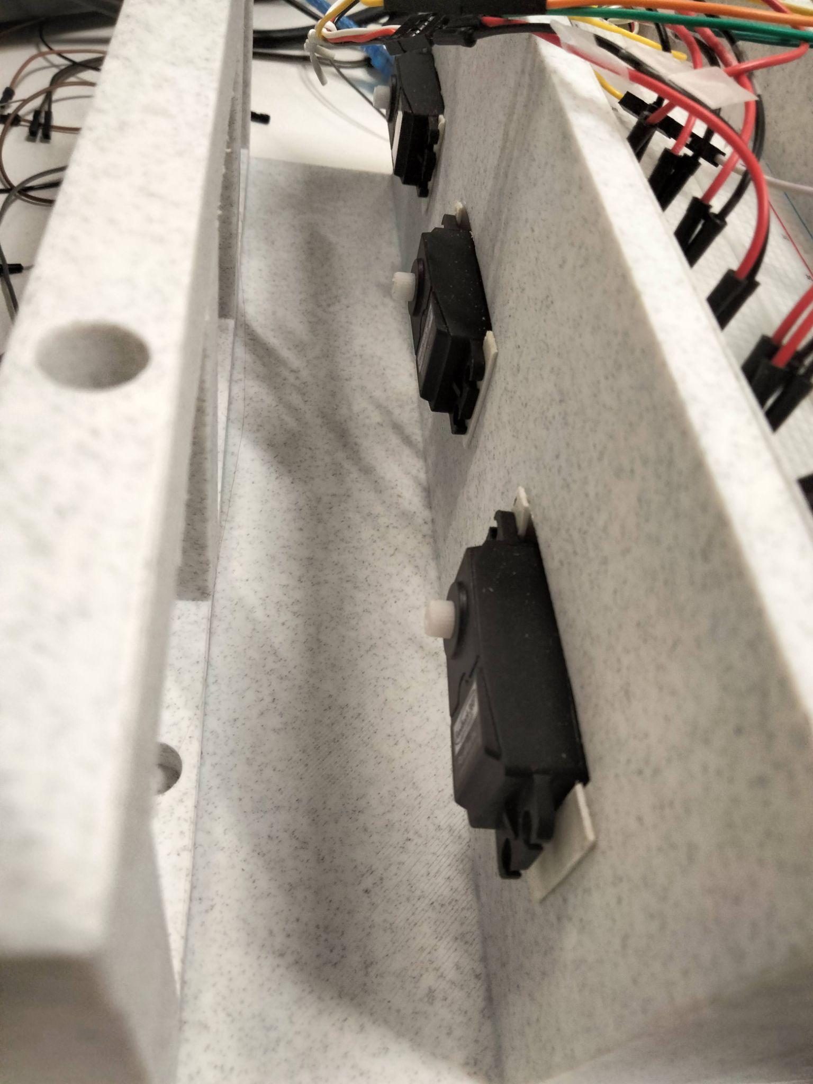
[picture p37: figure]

Paso 2: Montar los Cilindros de los motores

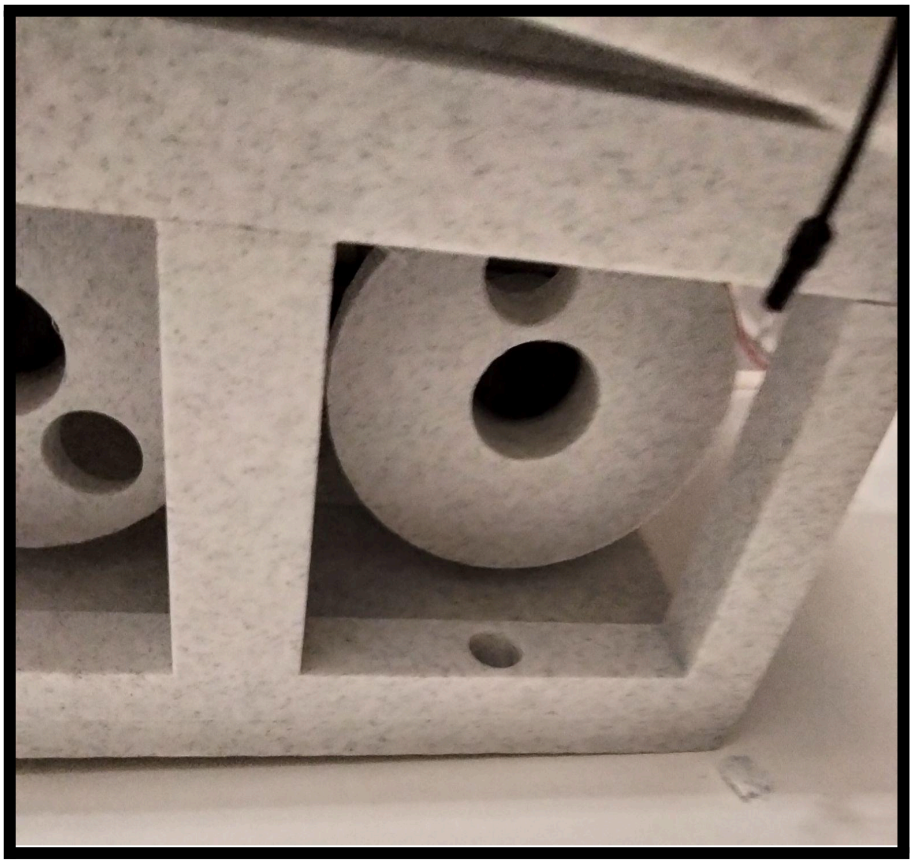
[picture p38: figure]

Paso 3: Montar el Cuadrado de la Pata

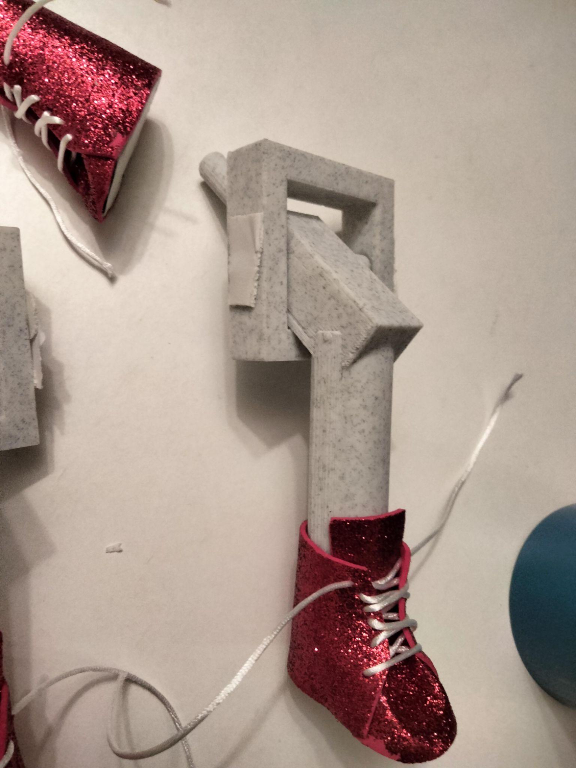
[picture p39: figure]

Paso 4: Colocar el Cilindro del Mecanismo

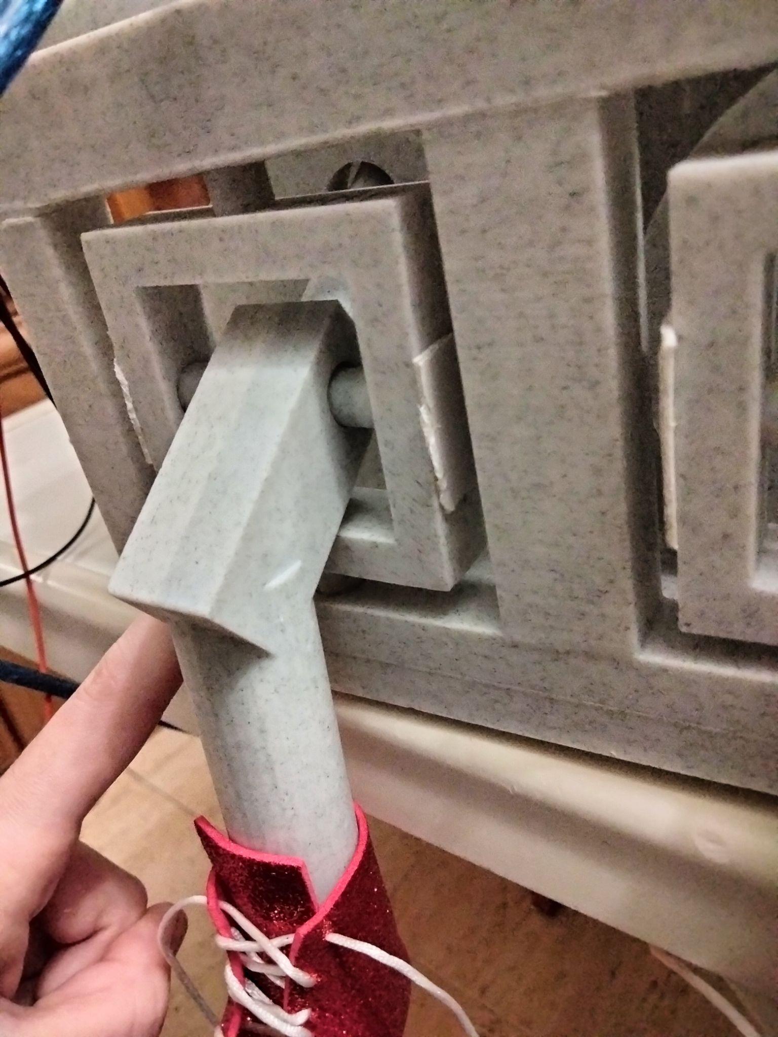
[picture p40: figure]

Tras montar y pegar todas las patas el robot debe quedar así:

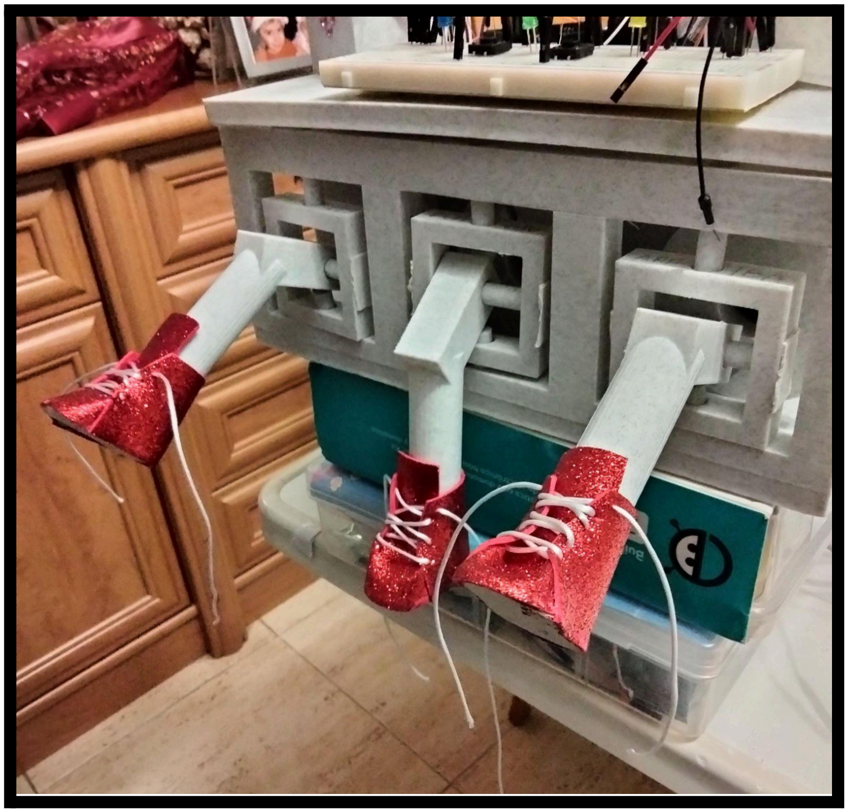
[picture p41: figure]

Pasos para montar el resto del robot:

Paso 1: Tapa modular

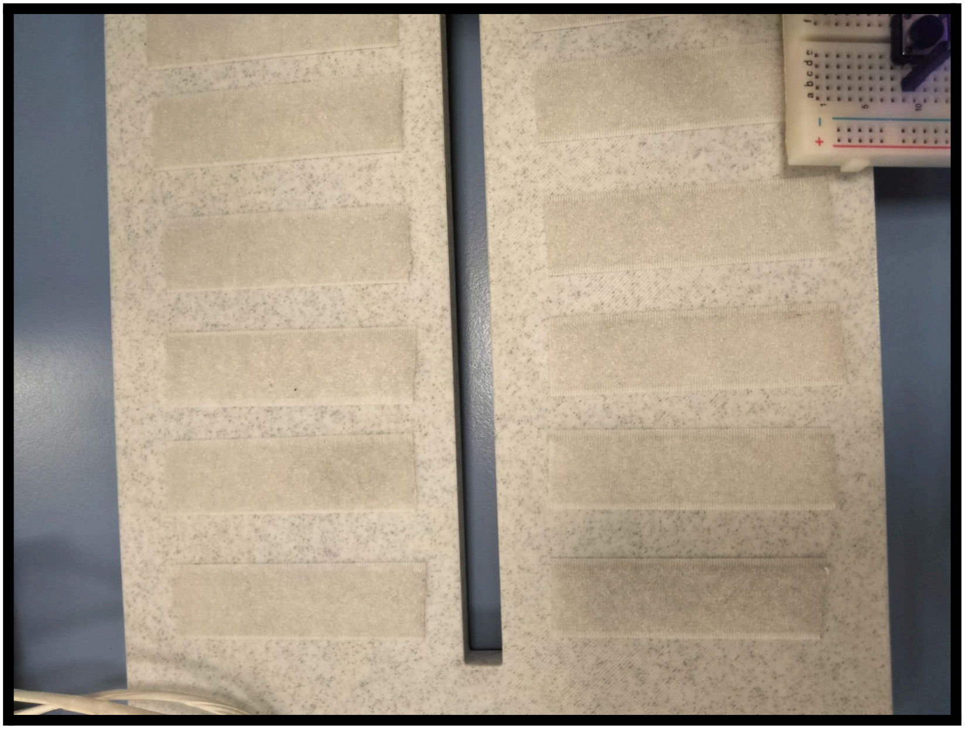
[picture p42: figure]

Paso 2: Colocar el Ultrasonido en el hueco de la Cabeza

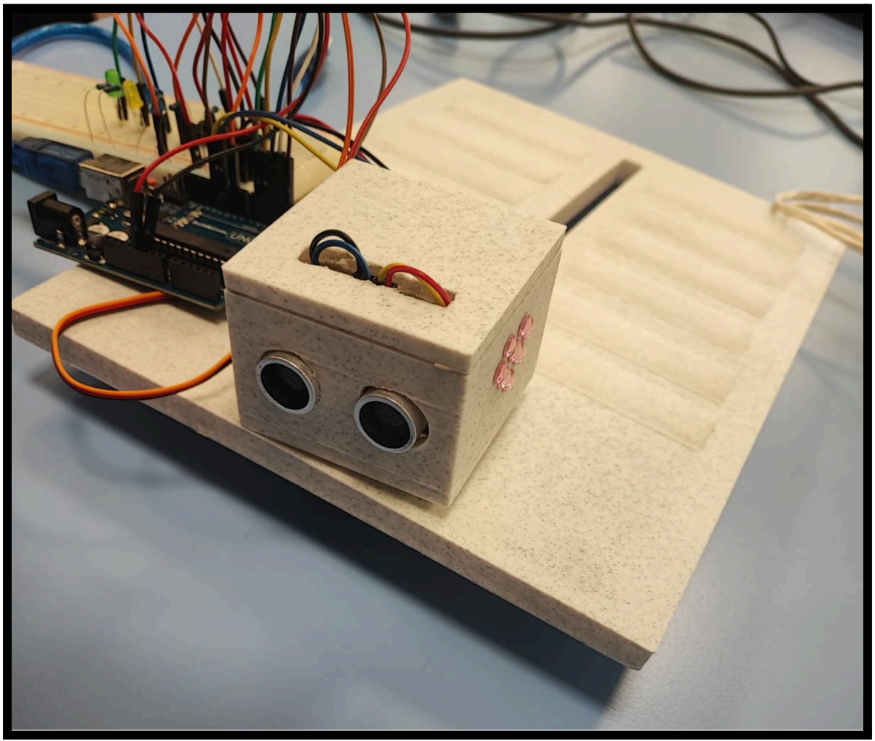
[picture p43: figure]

Paso 3: Introducir los Cables en la Cabeza

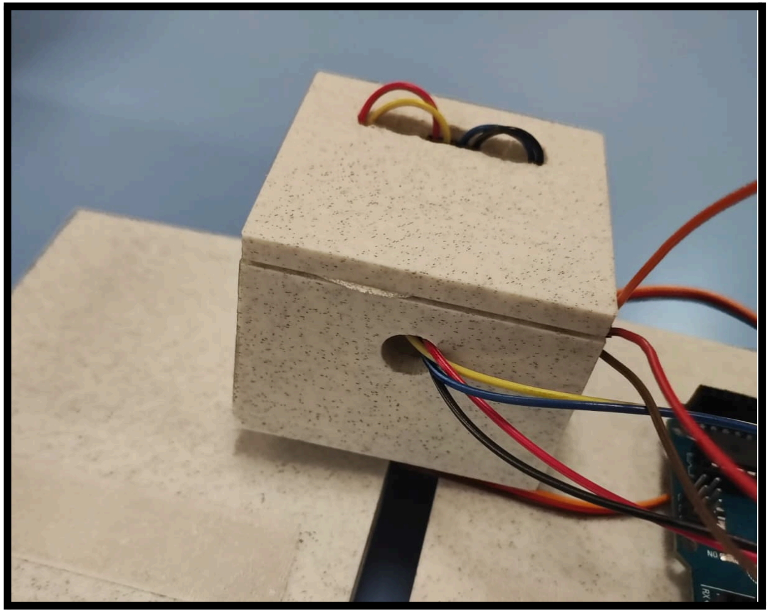
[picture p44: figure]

Paso 4: Acomodar los Cables y Tapar la Cabeza

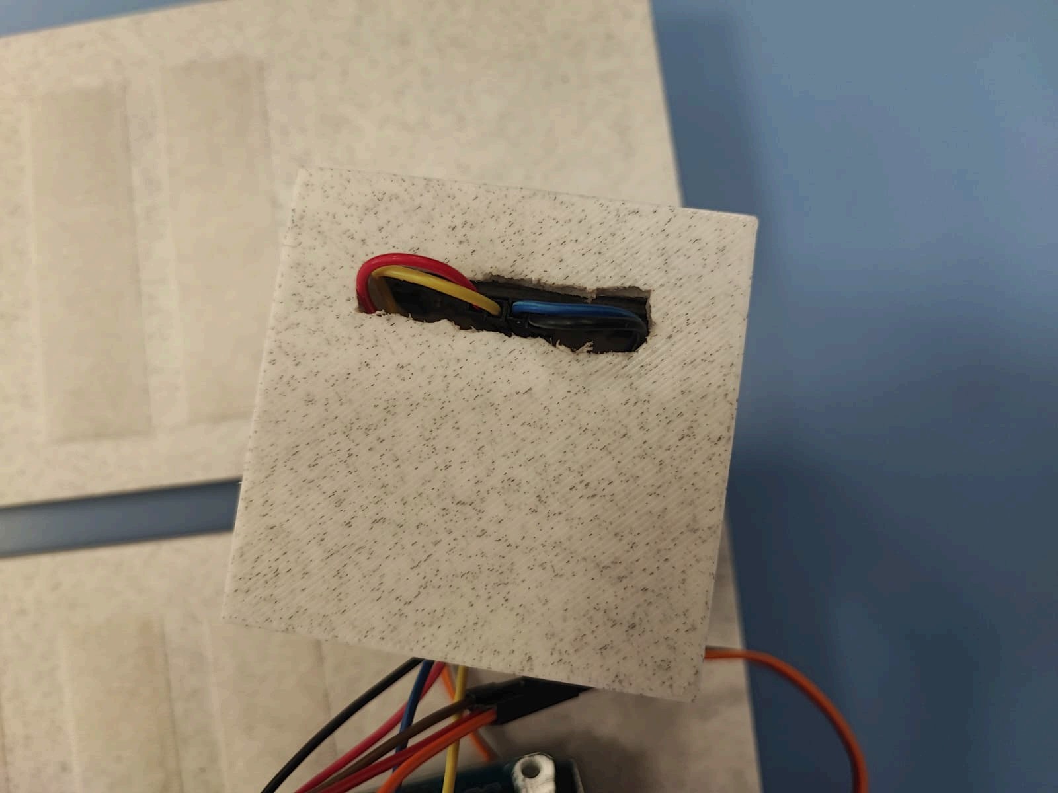
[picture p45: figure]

Paso 5: Cabeza a Tapa

Paso 6: Tapa a Base

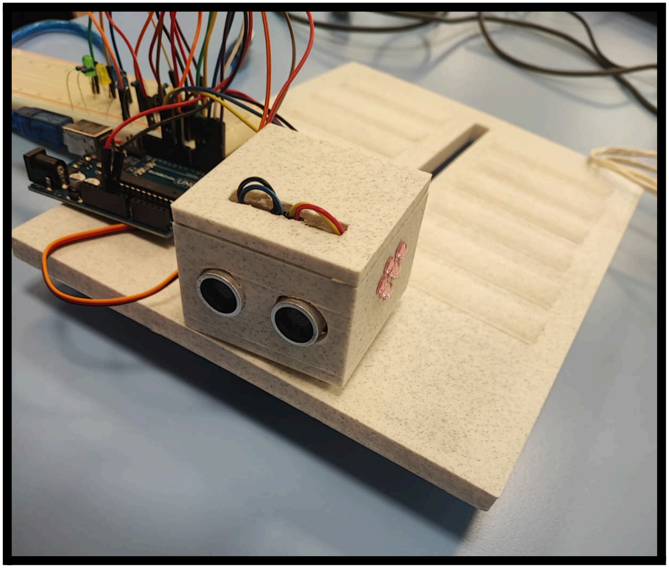
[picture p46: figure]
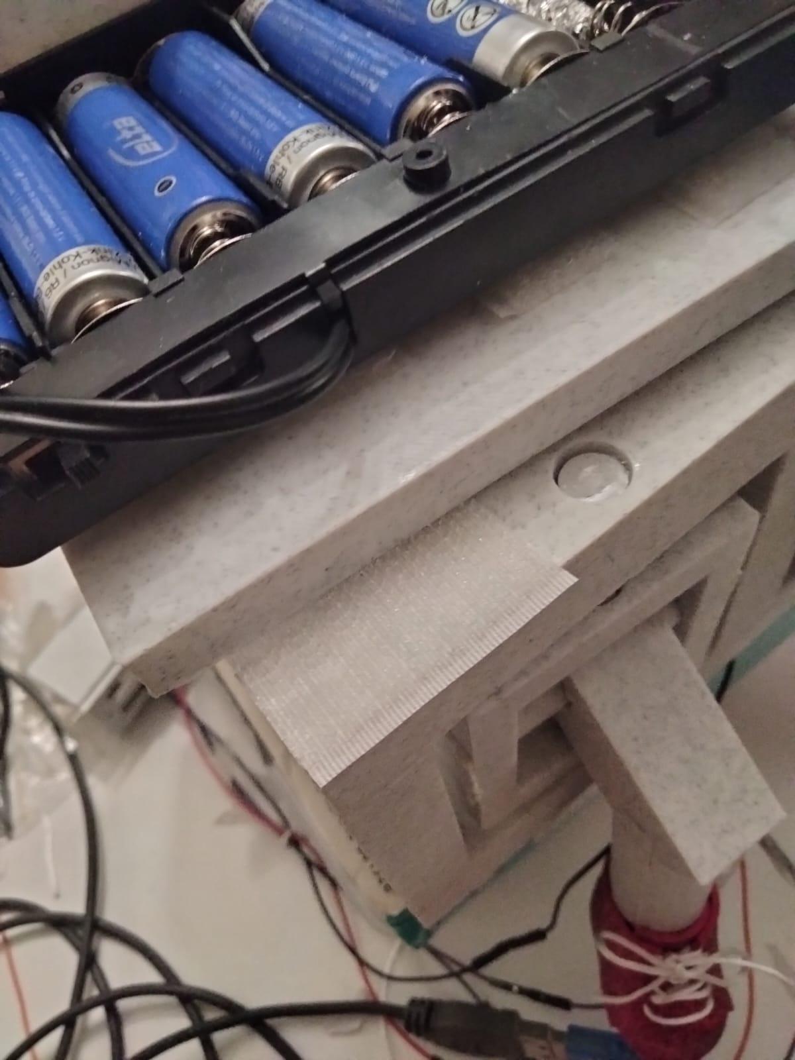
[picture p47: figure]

Paso 7: Repita los pasos anteriores para la cabeza inferior

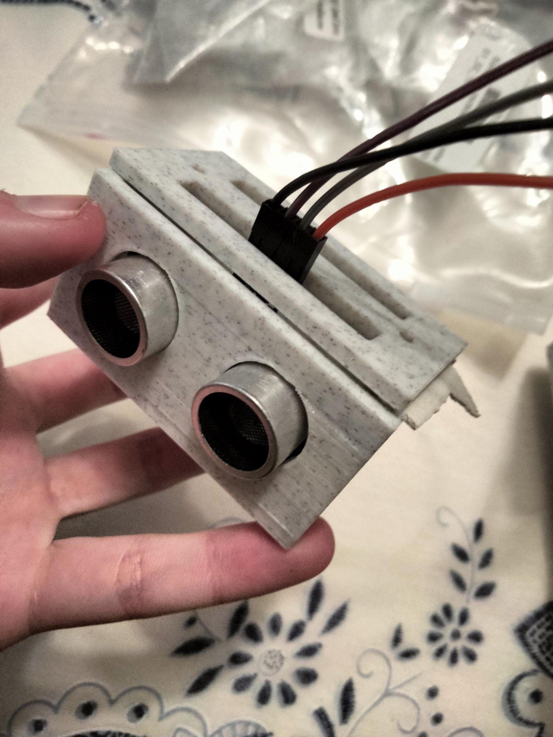
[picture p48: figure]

Tiene el robot montado ya

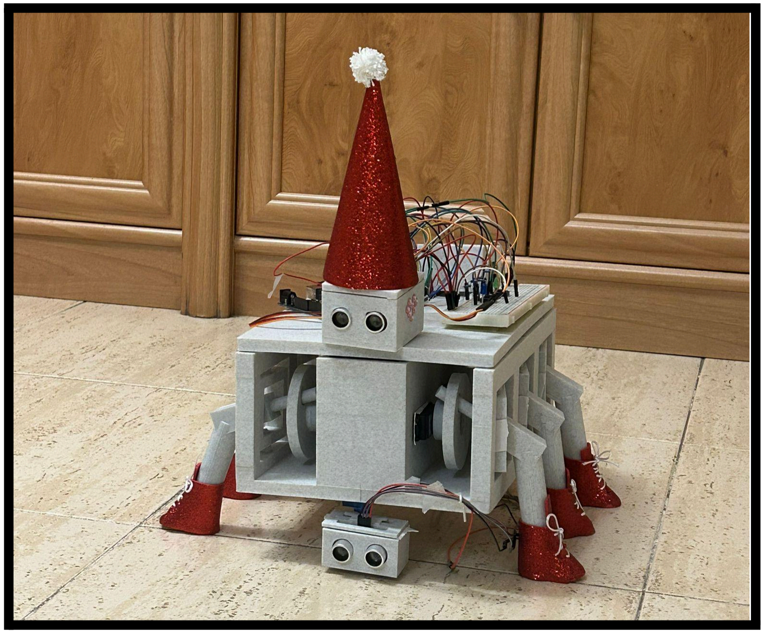
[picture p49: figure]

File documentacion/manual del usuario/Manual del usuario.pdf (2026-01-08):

# MANUAL DEL USUARIO

# PATUQUITO

# Mecatrónica

## IRENE DIEZ DE TORO

## SANDRA GONZALEZ ALONSO

VALERIA STOBINSKI ADILLO (https://www.aulavirtual.urjc.es/moodle/user/view.php?id=244258&course=237750)

## SILVIA CALVO CABELLO

## 4º INGENIERÍA ROBÓTICA SOFTWARE

12-12-2025


# Indice

# Introducción

Estimado usuario:

Este manual ha sido diseñado para proporcionar toda la información necesaria sobre las características, funciones y manejo adecuado del robot en cuestión. En sus páginas, encontrará las especificaciones técnicas del producto, instrucciones de uso, cuidados, mantenimiento y las recomendaciones para garantizar un rendimiento óptimo a lo largo de su vida útil.

Es de suma importancia que consulte este manual antes de poner en funcionamiento el robot, ya que contiene pautas esenciales sobre cómo operarlo de manera segura y eficiente. Asimismo, este documento le ayudará a comprender las capacidades del dispositivo, cómo aprovechar al máximo sus funciones y cómo resolver posibles inconvenientes que puedan surgir.

En caso de modificaciones o actualizaciones del producto, le instamos a revisar este manual regularmente para asegurarse de que sigue siendo relevante y de que está utilizando el robot de acuerdo con los procedimientos más actuales. Las modificaciones pueden afectar el rendimiento o los requisitos operativos, por lo que contar con la versión más reciente de este manual es fundamental para un uso adecuado y seguro.

Recuerde que el uso adecuado del robot no solo optimiza su rendimiento, sino que también contribuye a extender su vida útil. Si tiene alguna duda o requiere asistencia adicional, no dude en contactar a nuestro equipo de soporte.

Patuquito Patata es un robot hexápodo modular diseñado para ofrecer estabilidad y maniobrabilidad. Con seis patas que imitan el movimiento de una hormiga y una cabeza giratoria en forma de tortuga, que incorpora un sensor ultrasonido en sus ojos, este robot está construido para realizar desplazamientos precisos y evitar obstáculos de manera autónoma. Su estructura es robusta, con un chasis cuadrado y una capacidad única para transportar cargas pequeñas mientras navega en su entorno. Está concebido para moverse de manera eficiente mientras transporta una carga, y para evitar obstáculos con autonomía dentro de un espacio delimitado. Posee un par de botones que controlan el giro de su cabeza, controlado por dos modos y además incorpora una bandeja para la carga. Además, incorpora un diseño denominado “señor patata” que permite colocar los componentes de la tapa del cuerpo en la disposición que se desee, además de poseer espacio para incorporar cualquier componente exterior. Este posee dos modos de funcionamiento:

1. Modo de Desplazamiento Paralelo: En este modo, Patuquito Patata se desplaza de manera paralela a una pared, ajustando su trayectoria para seguirla con precisión.
2. Modo de Evasión de Obstáculos: Este modo permite que Patuquito Patata navegue de manera autónoma en un espacio delimitado, evitando obstáculos mientras se desplaza dentro de un área de 2 metros cuadrados, tocando 4 paredes..

¡ATENCIÓN! -> Precauciones Importantes

1. Apague siempre el hexápodo modular antes de manipularlo, realizar mantenimiento o cambiar las baterías.
2. No fuerce los conectores ni retire cables mientras el sistema esté energizado, ya que podría dañar la electrónica o provocar cortocircuitos. Compruebe las conexiones correctamente, con especial hincapié en las conexiones positivas y negativas.
3. Compruebe que el interruptor ha quedado realmente en posición OFF antes de trasladar, almacenar o intervenir el robot.
4. Evite encender el hexápodo modular sobre superficies inestables o cerca de bordes, para prevenir caídas o movimientos inesperados.
5. Mantenga sus manos alejadas de las patas articuladas al encenderlo, ya que pueden iniciar movimiento inmediatamente.
6. No meta ninguna extremidad en cualquier cavidad ni en la trayectoria de las patas y/o cabeza mientras el hexápodo modular se encuentre en funcionamiento. No deje a ningún menor sin supervisión, tiene peligro de realizar esta acción. Además, evite ponerse en la trayectoria lateral de las patas debido al riesgo de un aplastamiento en los pies debido a que no posee sensores laterales.
7. No manipule las baterías con las manos mojadas ni exponga el hexápodo modular a humedad mientras esté encendido.
8. No ingiera alimentos ni líquidos cerca y/o encima del hexápodo modular.
9. Procure no limpiar el producto con agua y/o otros productos de limpieza sobre zonas de corriente eléctrica. Solo limpie el chasis con un paño húmedo.
10. Si observa un comportamiento anómalo, apague el hexápodo modular de inmediato usando el interruptor principal.
11. Asegúrese de que las baterías estén correctamente instaladas y sin daños antes de encender el dispositivo. Por favor, compruebe y asegúrese que estén correctamente conectadas y no en reversa.
12. No deje el hexápodo modular encendido sin supervisión, especialmente durante pruebas o calibraciones.
13. Procure no taladrar ningún agujero adicional a los que ya vienen de fábrica en el chasis del hexápodo modular, podría correr peligro de romper y/o rajar la pieza principal.

14. Si alguna pieza se resquebraja, rompe o se deteriora, independientemente de la garantía del producto, por favor contacte con nuestro soporte para buscar una solución adecuada.

# Montaje

## Introducción al montaje

En este apartado se describen los pasos necesarios para el montaje correcto del robot. Es fundamental seguir las instrucciones cuidadosamente para garantizar un funcionamiento óptimo y seguro del dispositivo. Cada componente debe colocarse y fijarse correctamente, ya que cualquier error puede afectar la estabilidad y el desempeño del robot.

Este manual está diseñado para guiarle paso a paso, proporcionando instrucciones claras, recomendaciones de seguridad y consejos prácticos que faciliten el montaje incluso si es la primera vez que trabaja con este tipo de dispositivos. Al finalizar el montaje de todas las partes, el robot estará listo para la integración de los sistemas electrónicos y de control.

## Montaje de las patas

Introducción al montaje de una pata

Cada pata del robot es un componente fundamental que contribuye al movimiento, estabilidad y funcionalidad general del dispositivo. Por ello, es muy importante seguir cuidadosamente cada paso, asegurándose de que todos los elementos queden correctamente colocados y firmemente fijados.

Aunque en esta sección se describe únicamente el montaje de una pata, el procedimiento debe repetirse de manera idéntica para las seis patas del robot. Prestar atención a la orientación de los motores, la alineación de la base y la correcta fijación de cada componente garantizará que el robot funcione de manera estable y eficiente.

Pasos para montar una pata

Materiales necesarios:

- 1 Base (20 * 28 * 11 cm)
- 1 Tapa (20 * 28 * 1 cm)
- 6 Motores (cilindros de motor, radio 6 cm)
- 6 Patas

- 6 Cuadrados de patas (6 * 6 * 1.5 cm)
- 6 Cilindros traveseros para pata (6 cm de largo)
- 12 Cilindros mecanismo (3 cm de largo)
- 6 Cilindros motores ( 7.5 cm de radio)

Paso 1: Colocar los Motores

1. Tome los 6 motores y coloquelos en sus respectivos huecos en la base, asegurándose de que todos estén orientados en la misma dirección.
2. Saque los cables de los motores por el centro de la base para facilitar su conexión posterior.
3. A continuación, fije los motores a la base. Puede hacerlo aplicando pegamento resistente, silicona, cinta adhesiva de alta adherencia. Es importante que queden correctamente alineados y firmemente sujetos para evitar movimientos durante su funcionamiento

Paso 2: Montar los Cilindros de los motores

1. Desatornille el engranaje de los motores para poder colocar el cilindro entre el motor y el engranaje.
2. Coloque el cilindro de los motores entre el motor y el engranaje, asegurándose de que encaje correctamente.
3. Vuelva a atornillar el engranaje en su lugar, teniendo cuidado de no apretarlo en exceso ni dejarlo demasiado flojo. El tornillo debe quedar ajustado para evitar movimientos indeseados, pero sin dañar las piezas.

Paso 3: Montar el Cuadrado de la Pata

1. Tome un cuadrado de pata, una pata y un cilindro travesero.
2. Introduzca la pata dentro del cuadrado, asegurándose de que el agujero con tope en el cuadrado quede en la parte superior.
3. Alinee el hueco del cuadrado con el hueco correspondiente de la pata.
4. Inserte el cilindro travesero atravesando ambos, el cuadrado y la pata, de modo que queden firmemente unidos.

5. Fije el cilindro a los lados del cuadrado utilizando adhesivo o el método de fijación correspondiente, para evitar que se deslice o salga.

Paso 4: Colocar el Cilindro del Mecanismo

1. Coloque un cilindro mecanismo en la parte inferior del cuadrado de la pata.
2. Introduzca el cilindro en el hueco inferior del cuadrado de la base.
3. A continuación, coloque el cilindro superior del cuadrado en la parte superior y fíjelo en su lugar para asegurar que el mecanismo quede firme.
4. Verifique que el cilindro del mecanismo quede bien insertado y fijado al cuadrado de la pata.

Paso 5: Repetir el Proceso

Una vez montada la primera pata, repita este proceso para las otras cinco patas. Cuando haya terminado, su robot tendrá todas las patas montadas correctamente.

Pasos para montar el resto del robot:

Paso 1: Tapa modular

Este robot está pensado para que pueda colocar los componentes en distintas configuraciones según lo desee, para ello seleccione cuál va a ser la parte de arriba de la tapa, es necesario que coloque el velcro en la tapa creando varias filas a ambos lados de la rendija para pasar cables, a su vez coloque la otra parte del velcro en la parte inferior de los módulos, de las baterías, de la protoboard, la carga de pago, el arduino y cualquier otro módulo que desee crear.

Paso 2: Colocar el Ultrasonido en el hueco de la Cabeza

Para montar la cabeza, debe de observar que esta posee dos agujeros en una de las caras. Aquí deberá de meter y encajar el sensor ultrasonido.

Paso 3: Introducir los Cables en la Cabeza

Posteriormente, deberá de meter los cables que conectan al ultrasonido con el arduino en el agujero existente en la cara opuesta a la del sensor. Una vez pasados, debe de enchufarlos a las clavijas del sensor según corresponda.

Paso 4: Acomodar los Cables y Tapar la Cabeza

Tape y fije a la cabeza su tapa incorporada acomodando los cables por el agujero rectangular para simular estéticamente unas orejas. Por último, en la parte inferior de la cabeza fije de la forma que vea más conveniente la pieza blanca que se encaja en el servomotor.

Paso 5: Cabeza a Tapa
Fije en el hueco grande de la tapa el servomotor correspondiente al movimiento de la cabeza. Inserte la pieza blanca pegada en la cabeza en el servomotor (previamente instalado) de la tapa.

Paso 6: Tapa a base
Una vez estén montados los servomotores, los engranajes y las patas, y la cabeza; encaje la tapa modular encima del chasis. Esta viene incorporada con un velcro que la sujetará.

Paso 7: Repita los pasos anteriores para la cabeza inferior
Recuerde colocar bien los cables para que no se enreden con ninguna pata.

¡Enhorabuena! Ahora ha montado correctamente su robot

Pasos para montar una pata

Paso 1: Colocar los Motores


Paso 2: Montar los Cilindros de los motores

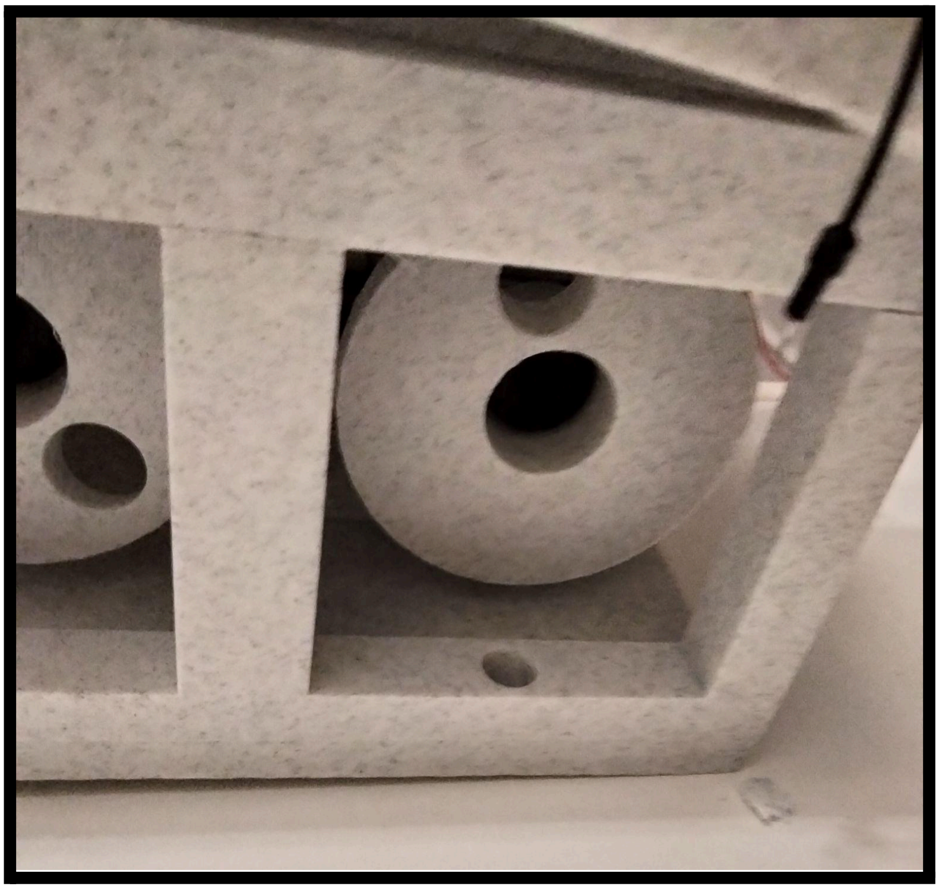
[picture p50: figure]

Paso 3: Montar el Cuadrado de la Pata


Paso 4: Colocar el Cilindro del Mecanismo


Tras montar y pegar todas las patas el robot debe quedar así:

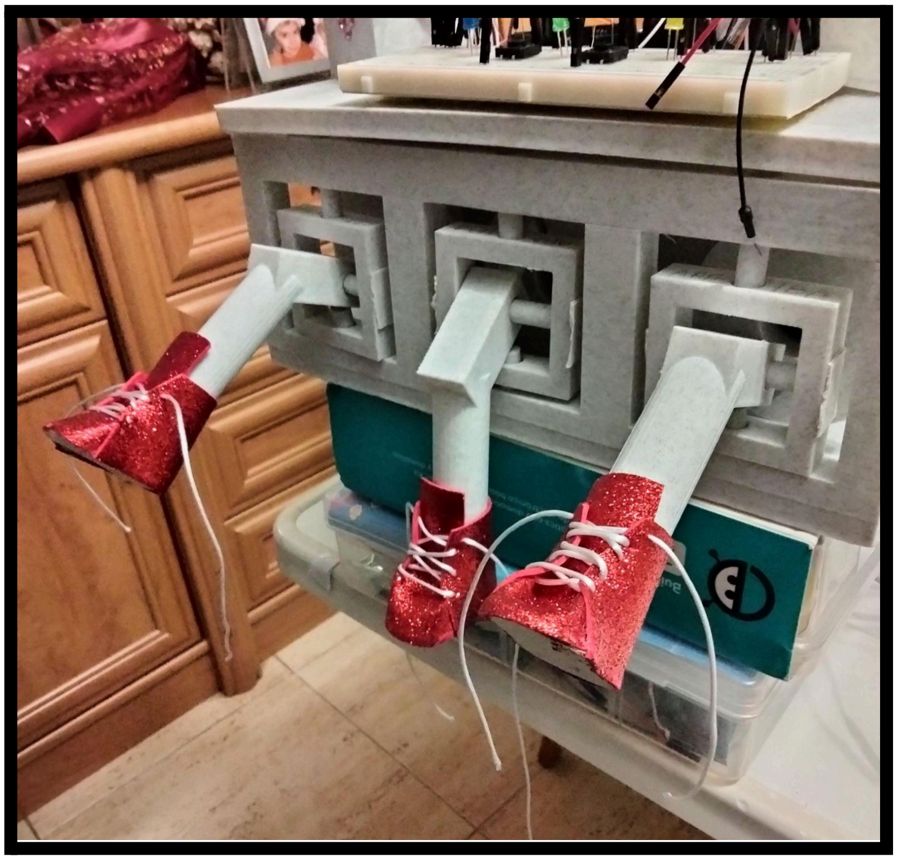
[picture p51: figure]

Pasos para montar el resto del robot:

Paso 1: Tapa modular

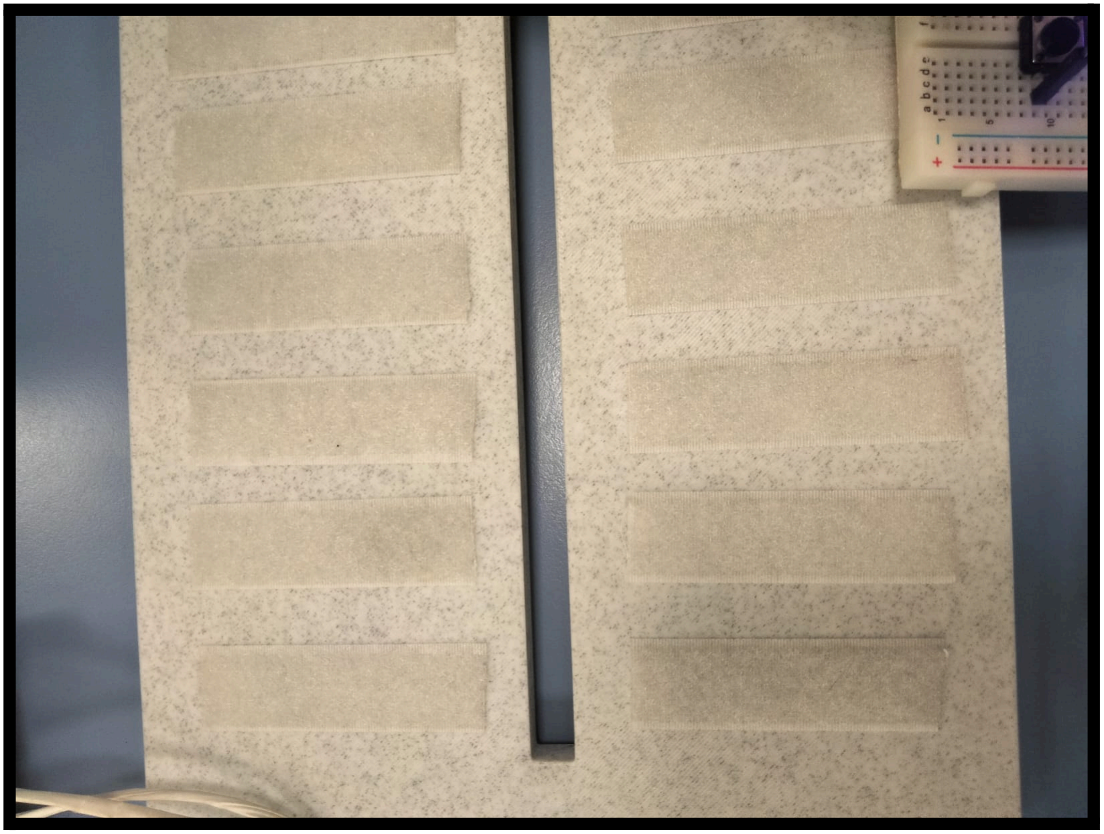
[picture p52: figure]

Paso 2: Colocar el Ultrasonido en el hueco de la Cabeza

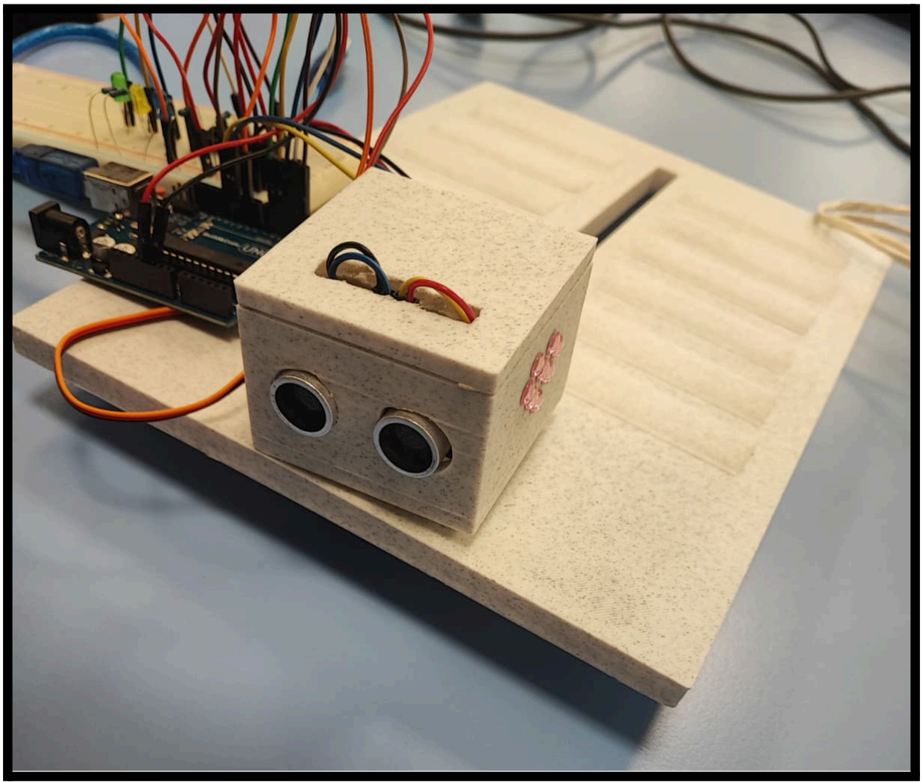
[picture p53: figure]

Paso 3: Introducir los Cables en la Cabeza

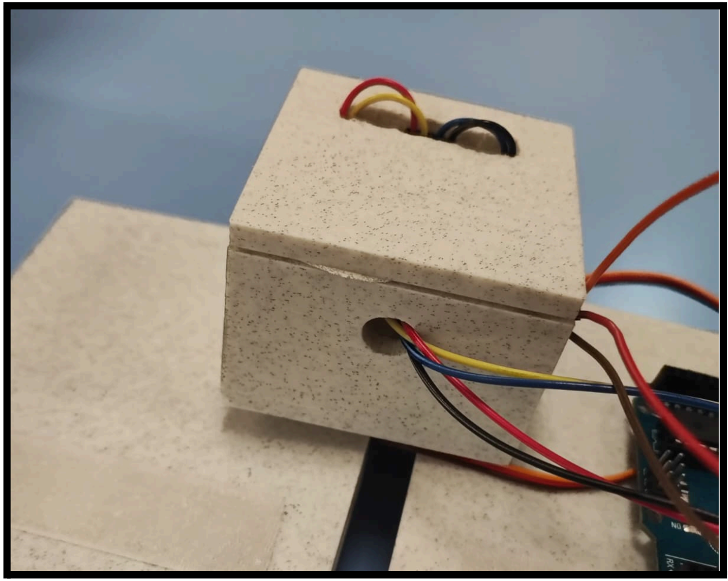
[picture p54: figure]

Paso 4: Acomodar los Cables y Tapar la Cabeza


Paso 5: Cabeza a Tapa

Paso 6: Tapa a Base

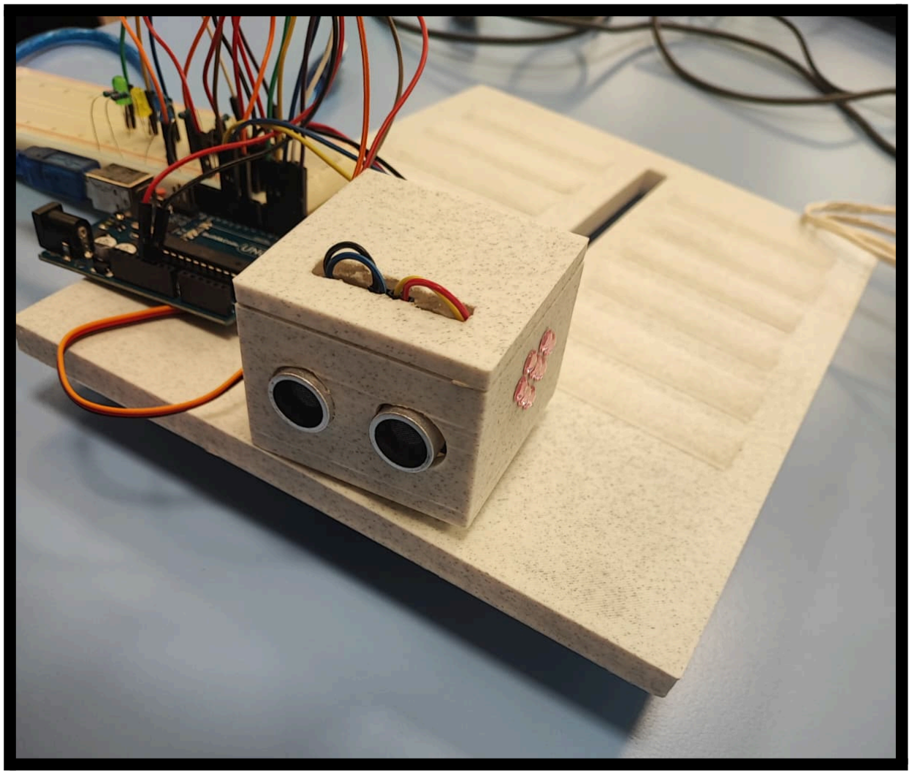
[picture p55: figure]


Paso 7: Repita los pasos anteriores para la cabeza inferior


Tiene el robot montado ya

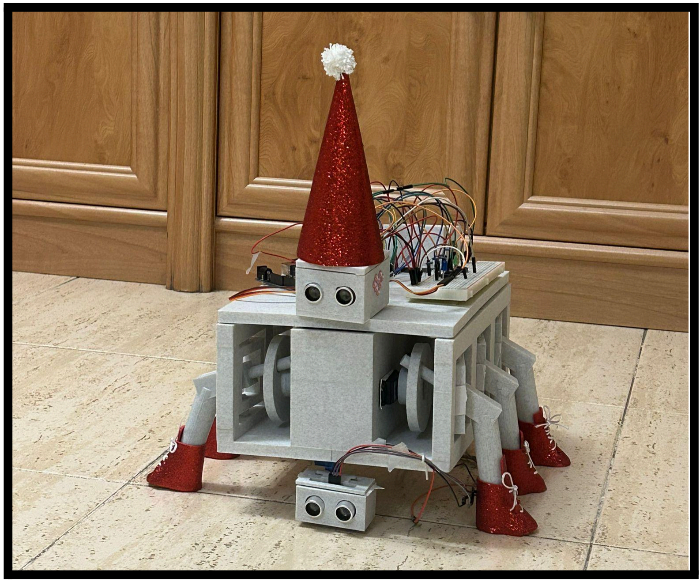
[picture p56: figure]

# Preparación para el uso

## Encendido y apagado seguro

Para encender o apagar el robot hexápodo, utilice exclusivamente el interruptor ON/OFF ubicado en el compartimento de pilas o baterías.

¡ATENCIÓN! Al encender el robot, las patas realizan un movimiento automático para colocarse en la posición inicial de funcionamiento.

¡ATENCIÓN! No desconecte ningún cable ni retire la batería sin haber apagado previamente el robot de manera adecuada.

Indicaciones y Precauciones

- No encienda ni apague el robot repetidamente en intervalos muy cortos. Esto puede generar picos de corriente perjudiciales para la electrónica interna.
- Después de apagar el robot, espere unos segundos antes de volver a encenderlo, permitiendo que los circuitos y capacitores se descarguen correctamente.
- Verifique el estado del interruptor ON/OFF antes de utilizarlo. No debe presentar holguras, daños ni falsos contactos, ya que podrían causar interrupciones eléctricas o fallos de funcionamiento.
- Revise el estado de la batería y los conectores antes de encender el robot. No lo active si las baterías están dañadas, mal colocadas o con un nivel de carga insuficiente.
- Si el robot presenta comportamientos anómalos o movimientos inesperados, apáguelo inmediatamente mediante el interruptor ON/OFF y espere unos segundos antes de intentar encenderlo nuevamente.
- Apague siempre el robot antes de retirar la batería. Cuando lo haga, sujete el conector desde la carcasa del mismo y nunca tire directamente de los cables.

## Carga de la batería:

Es esencial que la batería del robot esté correctamente cargada para garantizar su funcionamiento óptimo. Para ello, el robot está equipado con un portapilas que utiliza pilas AA recargables. Es importante asegurarse de que las pilas estén completamente cargadas antes de poner el robot en funcionamiento. Las pilas deben cargarse de manera periódica, siguiendo las recomendaciones del fabricante para evitar su desgaste prematuro y asegurar una duración prolongada.

Además, las pilas deben proporcionar una tensión mínima de 7 V y 8 A para asegurar que el robot opere de manera eficiente. Si la carga desciende por debajo de este umbral, es posible que el rendimiento del robot se vea afectado, lo que podría ocasionar fallos en su operación o una reducción en el tiempo de funcionamiento continuo.
Por lo tanto, es fundamental mantener un control regular sobre el nivel de carga de las pilas y recargarlas cuando sea necesario, para asegurar que el robot se mantenga en condiciones óptimas de funcionamiento

## Instalación del software:

Si usted desea realizar cambios en el código del robot, visualizar datos o probar códigos de prueba (por ejemplo, aquellos destinados únicamente al movimiento de las patas), es necesario instalar el entorno de desarrollo integrado (IDE) de Arduino. A continuación, se detallan los pasos para llevar a cabo este proceso.

1. Descarga del IDE de Arduino

Para comenzar, deberá descargar e instalar el IDE de Arduino en su ordenador. Los pasos son los siguientes:

- Windows / macOS / Linux:
Acceda al sitio web oficial de Arduino y descargue la versión correspondiente a su sistema operativo. Una vez descargado el archivo, siga las instrucciones proporcionadas por el instalador.
2. Obtención del código fuente

Una vez instalado el IDE, será necesario obtener los archivos de código requeridos para el funcionamiento del robot:

- Diríjase al repositorio correspondiente al proyecto, donde encontrará los archivos necesarios. https://github.com/sandrag4/mecatronica-patuquito
- Entre ellos se incluye un código de prueba diseñado específicamente para verificar el correcto funcionamiento de los motores y las patas del robot.
3. Carga del código en el robot

Cuando disponga de los archivos necesarios, siga los pasos a continuación:

1. Abra el archivo .ino en el IDE de Arduino.
2. Conecte el robot a su ordenador mediante el cable adecuado.
3. En el IDE, seleccione el puerto correcto y la placa correspondiente desde el menú Herramientas.
4. Presione el botón Subir para cargar el código en el robot.

Recomendación: Verificación del funcionamiento
Se recomienda iniciar siempre con el código de prueba. Este permitirá comprobar que los motores y las patas del robot funcionan de manera correcta antes de realizar modificaciones más avanzadas. Si el comportamiento es el esperado, podrá continuar con ajustes adicionales según sus necesidades.

# Modos de operación

## Indicadores luminosos

El robot está equipado con tres indicadores luminosos (LEDs) que informan sobre el estado de funcionamiento y el modo activo. A continuación se describen sus funciones:

LED Verde – Estado Operativo
El encendido del LED verde indica que el robot se encuentra funcional y operativo.
Una vez iluminado, confirma que el sistema ha iniciado correctamente y que las patas del robot ya se han posicionado en la postura inicial de funcionamiento tras el encendido.

LED Azul – Modo Seguimiento de Pared
El LED azul indica que el robot está ejecutando el modo de uso “Seguimiento de Pared”, en el cual se desplaza siguiendo una pared o borde sin incorporar detección ni evasión de obstáculos.

LED Amarillo – Modo Exploración con Evitación de Obstáculos
El LED amarillo señala que el robot está funcionando en el modo “Exploración con Evitación de Obstáculos”.
En este modo, el robot recorre y detecta las cuatro paredes de una sala, identificando obstáculos en su trayectoria y realizando maniobras de evasión de forma automática.

## Modos de marcha

El robot cuenta con dos modos de marcha que se pueden seleccionar según la necesidad de la tarea. Para seleccionar un modo, simplemente mantenga presionado el botón correspondiente en la protoboard y compruebe que al soltar el LED del modo elegido se ilumine. A continuación se describen los dos modos de funcionamiento disponibles:

Modo 1: Seguimiento de Pared

El Modo de Seguimiento de Pared permite al robot seguir una pared durante un recorrido de aproximadamente un metro.

- Función: En este modo, el robot utiliza su sensor ultrasónico para detectar la pared. Si en algún momento se desvía de la pared, el robot ajustará su posición para mantenerse paralelo a la pared de forma continua.
- Importante: Este modo no detecta obstáculos. Cualquier objeto en el camino será interpretado como una extensión de la pared, y el robot continuará su marcha sin realizar ninguna maniobra evasiva.

Modo 2: Exploración con Evitación de Obstáculos

El Modo de Exploración con Evitación de Obstáculos permite al robot explorar el entorno de la siguiente manera:

- El robot se dirige primero hacia la primera pared, luego realiza un giro de 90 grados para orientarse hacia la pared contigua dereha.
- A continuación, se dirige hacia la pared contigua inferior y, una vez alcanzada, realiza otro giro de 90 grados para continuar hacia la última pared.
- Evasión de Obstáculos: Si durante su recorrido el robot detecta un obstáculo (menos de 10 cm de largo, si es más largo lo puede detectar como pared), lo esquivará automáticamente. El robot realizará un giro para evitar el obstáculo y continuará su camino una vez que haya avanzado lo suficiente para no detectarlo más.

Finalización del Modo
Al finalizar cualquiera de los dos modos, el LED de modo se apagará, indicando que el robot ha completado su recorrido. En este punto, podrá volver a seleccionar el modo que desee utilizando el botón de la protoboard correspondiente.

# Procedimiento de prueba inicial

## Verificación de servomotores y sensores

Para proceder con la funcionalidad del hexápodo modular, se deben realizar una serie de comprobaciones con respecto a los componentes de este. Estas verificaciones iniciales son esenciales para asegurar que todos los elementos mecánicos y electrónicos se encuentren en buen estado antes de ejecutar movimientos más complejos.

Para ello, descargue el código de prueba inicial con el fin de ejecutarlo y comprobar que todo funcione correctamente. Este código permite evaluar el estado básico de los servomotores y sensores, realizando movimientos simples y lecturas iniciales que ayudan a identificar posibles fallos. Durante la prueba:

- Asegúrese de que cada servomotor responde adecuadamente y sin realizar movimientos bruscos o erráticos.
- Verifique que no existan ruidos anómalos, vibraciones excesivas ni calentamientos inesperados.
- Compruebe que los sensores entregan valores coherentes y dentro de los rangos esperados.
- Revise las conexiones físicas, cables y alimentaciones para confirmar que no haya elementos sueltos o mal conectados.

## Ejemplo de secuencia de movimiento

Con los servomotores y sensores verificados, es momento de realizar una prueba básica de movimiento para comprobar que el robot puede ejecutar tareas de manera eficiente.
Pasos para la secuencia de movimiento:
1. Seleccionar el modo de operación: Elija uno de los modos de funcionamiento disponibles explicados en la sección de Modos de operación (Seguimiento de Pared o Exploración con Evitación de Obstáculos) mediante el botón en la protoboard.
2. Ejecutar la secuencia de movimiento: Observe el comportamiento del robot al ejecutar la secuencia de movimiento seleccionada. Dependiendo del modo de operación, el robot deberá de seguir las instrucciones especificadas de cada modo descritas en la sección de Modos de operación.
3. Revisión de la interacción con el entorno: Verifique que el robot sea capaz de detectar obstáculos correctamente y que realice las maniobras de evasión según lo esperado. Si se detecta algún fallo en la maniobra, consulte la sección de solución de problemas.
4. Finalización de la prueba: Si el robot ha seguido la secuencia correctamente, los indicadores luminosos confirmaran que el sistema está funcionando adecuadamente. En caso contrario, consulte la sección de solución de problemas o contacte con nuestro soporte técnico.

# Solución de problemas comunes

Estimado usuario, este apartado recoge los problemas más habituales y sus posibles soluciones. En caso de experimentar algún fallo, le recomendamos revisar esta sección en busca de ayuda. Si su incidencia no aparece descrita aquí, no dude en contactar con nuestro servicio de soporte técnico para recibir un asesoramiento más detallado.

- El hexápodo modular no enciende.

Revise cuidadosamente la conexión de las baterías. Asegúrese de que los terminales están firmemente encajados y de que el nivel de carga es suficiente para garantizar el funcionamiento del sistema. Una batería con voltaje insuficiente o una mala conexión puede generar fallos similares a los provocados por un error en el cableado. Si, tras esta comprobación, la incidencia continúa, verifique que todas las conexiones eléctricas se han establecido de acuerdo con lo especificado. Para ello, consulte el esquema del circuito incluido en la sección “Esquema de cableado” y confirme que cada componente está conectado en la posición y orientación correctas. A continuación, inspeccione físicamente cada clavija para asegurarse de que no exista ningún cable parcialmente insertado, flojo o con mal contacto, ya que este tipo de fallos pueden provocar interrupciones intermitentes en el suministro eléctrico o en la transmisión de señales.

- Los servos no se mueven.

Verifique que las conexiones estén correctamente realizadas y que los cables no presenten daños, falsos contactos o conexiones sueltas, ya que incluso un contacto parcial puede impedir su funcionamiento. A continuación, ejecute el código de prueba proporcionado para confirmar si los servos responden correctamente a las señales de control. Si, tras estas comprobaciones, los servos continúan sin moverse, asegúrese de que están recibiendo la alimentación adecuada de acuerdo con sus especificaciones, ya que un voltaje insuficiente puede generar fallos intermitentes o impedir el movimiento. También revise que no existan daños internos, sobrecalentamiento o señales de quemado en los servos. Finalmente, como medida adicional de diagnóstico, pruebe a cambiar su posición en el código o en el controlador, para descartar posibles bloqueos mecánicos o errores en la señal de control que impidan el giro.

- Movimiento irregular o pérdida de equilibrio.

Revise el montaje de todas las piezas de las patas, asegurándose de que estén correctamente alineadas y firmemente sujetas. Verifique también que el contacto con los motores esté adecuado, sin holguras ni desajustes que puedan afectar la transmisión del movimiento. A continuación, ejecute el código de prueba para comprobar que los motores y las patas responden de manera coordinada según el ciclo de movimiento esperado. Este procedimiento permitirá identificar si la causa del problema es mecánica o de programación, facilitando su corrección de manera precisa.

# Advertencias y recomendaciones

- Evitar sobrecargas.
No exceda la capacidad máxima del sistema o dispositivo. Las sobrecargas pueden provocar fallos de funcionamiento, reducir la vida útil de los componentes y generar riesgos de seguridad.
- Mantenimiento básico.
Realice revisiones periódicas para garantizar el correcto funcionamiento del equipo. Mantenga limpias las superficies, verifique conexiones y compruebe que no existan piezas sueltas o deterioradas.
- Uso en entornos seguros
Utilice el dispositivo únicamente en entornos controlados (especificados en las pruebas 1 y 2 y libres de condiciones extremas (temperaturas muy altas o bajas, humedad excesiva, polvo, vibraciones intensas). Esto evita daños tanto en el equipo como en el usuario.
- No intentar recrear el proyecto.
El diseño, los componentes y la configuración utilizados forman parte de un montaje específico. Intentar replicar el proyecto sin la información técnica completa puede resultar peligroso y comprometer la seguridad del usuario.
- No modificar ni reprogramar el sistema ni plagiar el proyecto.
Cualquier alteración del software, firmware o parámetros internos puede causar fallos inesperados, pérdida de control, daños materiales o riesgos de seguridad. Utilice el equipo tal como se ha entregado y configurado. Evite plagiar el proyecto debido a que puede enfrentarse contra una demanda legal.

# Esquema del cableado

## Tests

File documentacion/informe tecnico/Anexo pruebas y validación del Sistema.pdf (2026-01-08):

# Pruebas y validación del Sistema

Con el objetivo de garantizar el correcto funcionamiento del robot hexápodo, se ha llevado a cabo un proceso de pruebas estructurado que abarca tanto la validación electrónica y mecánica como la verificación funcional y de comportamiento. Las siguientes pruebas se han realizado de forma secuencial, asegurando que cada subsistema opere correctamente antes de proceder con el siguiente.

## Pruebas de componentes electrónicos

Prueba de los botones de control

El propósito de esta prueba es verificar el correcto funcionamiento de los botones integrados en la interfaz de usuario.
Para ello, se pulsa cada botón de manera individual mientras se observa la respuesta del sistema a través del encendido de los LED asociados. Cada botón debe activar un LED distinto, confirmando así que la lectura digital del pulsador es correcta, que el cableado no presenta fallos y que la placa de control interpreta adecuadamente las señales de entrada.

Prueba del sensor de ultrasonidos

Esta prueba tiene como objetivo comprobar que el sensor de ultrasonidos realiza correctamente la medición de distancias.
Se coloca un objeto a distintas distancias conocidas (por ejemplo: 10 cm, 20 cm, 40 cm) y se verifica que el valor reportado por el sensor es coherente con las distancias reales. Resultados consistentes dentro de un margen razonable validan tanto el sensor como su configuración y su comunicación con la controladora.

Prueba de las baterías

La comprobación del estado de las baterías es fundamental para garantizar la autonomía y seguridad del sistema.
Utilizando un multímetro, se mide el voltaje de la batería asegurando que se encuentra dentro del rango operativo especificado. Además, se realiza una comprobación del suministro de corriente para confirmar que la batería es capaz de entregar la potencia necesaria para los motores y la electrónica durante el funcionamiento. Valores por debajo de lo esperado podrían indicar deterioro o necesidad de recarga.

Prueba de los motores

El objetivo de esta prueba es comprobar el correcto funcionamiento individual de cada motor.
Se utiliza un código de prueba que activa los motores secuencialmente, encendiendo uno a la vez y posteriormente apagándolo antes de pasar con el siguiente. Con esto se verifica que:

- No existen motores bloqueados.
- La señal PWM llega correctamente.
- No hay interferencias eléctricas entre canales.

## Pruebas mecánicas y de montaje

Prueba de montaje estructural

Antes de realizar pruebas dinámicas, se verifica que todas las piezas del robot han sido ensambladas correctamente.
Se comprueba que cada elemento encaja según el diseño y que no existen holguras excesivas. Posteriormente, se evalúa manualmente el movimiento de los mecanismos de las patas, desplazando los cilindros y articulaciones para asegurar que no existen bloqueos mecánicos. Esta prueba valida tanto el diseño mecánico como la calidad del montaje.

## Pruebas funcionales del robot

Prueba 1: Desplazamiento hacia adelante

Se evalúa si el robot es capaz de avanzar de manera estable y continua.
Para ello, se ejecuta el programa básico de locomoción hacia adelante y se verifica que todas las patas realizan la secuencia de movimiento correcta, que no existen deslizamientos inesperados y que la trayectoria es rectilínea.

Prueba 2: Giro controlado

El objetivo es comprobar si el robot puede realizar giros sobre su propio eje o en trayectoria curva.
Se activa la rutina de giro y se verifica que el movimiento es fluido y que la dirección coincida con lo esperado (derecha o izquierda). Observando posibles desbalances o errores de sincronización entre patas.

Prueba 3: Giro a 90 grados

Se solicita al robot que realice un giro de exactamente 90° tanto hacia la derecha como hacia la izquierda.
Con la ayuda de una escuadra, referencias en el suelo o mediciones angulares, se comprueba si el giro ejecutado se ajusta a lo programado. Esta prueba valida los algoritmos de movimiento y la sincronización de las patas durante maniobras de rotación.

## Pruebas de modos de operación

Prueba 5: Validación del Modo 1 – Seguimiento de pared

El objetivo de esta prueba es comprobar que el robot puede caminar en paralelo a una pared sin desviarse. Para que esto funcione bien, lo primero es confirmar que el sensor de ultrasonidos mide la distancia de forma correcta y que los valores no saltan por interferencias. El sistema tiene que estar seguro de que lo que ve es la pared real para poder ajustar el rumbo con precisión.

A medida que el robot avanza, compara la distancia que mide el sensor con la que tiene guardada como ideal. Si nota que se está pegando mucho a la pared, el robot debe reaccionar alejándose un poco; si se separa demasiado, tiene que corregir para acercarse de nuevo. La prueba se da por buena si el robot es capaz de recorrer un metro manteniendo esa distancia constante, demostrando que las correcciones son el resultado de una medición fiable.

Prueba 6: Validación del Modo 2 – Exploración con evitación de obstáculos

En esta prueba nos centramos en que el robot sepa diferenciar perfectamente entre una pared y un obstáculo suelto. Es fundamental comprobar que, cuando detecta algo, el robot se asegure de que es un obstáculo de verdad antes de hacer nada. Para esto, usamos una doble comprobación: el sistema solo da el aviso de "obstáculo" si el sensor de abajo detecta algo pero el de arriba tiene el camino libre. Esto evita que el robot se confunda y trate de esquivar una pared o que se mueva por un error de lectura.

Una vez que el robot está seguro de que hay un objeto delante y sabe a qué distancia exacta está, pone en marcha la maniobra de evasión. Primero mira si tiene hueco por la derecha y, si no, elige la izquierda. Después, da un giro de 90°, avanza lo suficiente para dejar atrás el objeto y vuelve a girar otros 90° para recuperar su camino original. Lo importante aquí es que el robot no solo esquive, sino que lo haga con margen suficiente para no chocar al retomar su ruta.

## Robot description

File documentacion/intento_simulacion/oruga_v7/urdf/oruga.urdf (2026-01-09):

<robot name="oruga" version="1.0">
  <joint name="Cone.001_link_joint" type="fixed">
    <origin rpy="3.14159 -0.00000 3.14159" xyz="0.00000 -0.01800 -0.04000"/>
    <parent link="Cube.002_link"/>
    <child link="Cone.001_link"/>
  </joint>
  <joint name="Cone.002_link_joint" type="fixed">
    <origin rpy="3.14159 -0.00000 3.14159" xyz="0.00000 -0.01800 -0.04000"/>
    <parent link="Cube.004_link"/>
    <child link="Cone.002_link"/>
  </joint>
  <joint name="Cone.003_link_joint" type="fixed">
    <origin rpy="3.14159 -0.00000 3.14159" xyz="0.00000 0.01800 -0.04000"/>
    <parent link="Cube.005_link"/>
    <child link="Cone.003_link"/>
  </joint>
  <joint name="Cone.004_link_joint" type="fixed">
    <origin rpy="3.14159 -0.00000 3.14159" xyz="0.00000 0.01800 -0.04000"/>
    <parent link="Cube.006_link"/>
    <child link="Cone.004_link"/>
  </joint>
  <joint name="Cone.005_link_joint" type="fixed">
    <origin rpy="3.14159 -0.00000 3.14159" xyz="0.00000 0.01800 -0.04000"/>
    <parent link="Cube.007_link"/>
    <child link="Cone.005_link"/>
  </joint>
  <joint name="Cone_link_joint" type="fixed">
    <origin rpy="3.14159 -0.00000 3.14159" xyz="0.00000 -0.01800 -0.04000"/>
    <parent link="Cube.001_link"/>
    <child link="Cone_link"/>
  </joint>
  <joint name="Cube._derecha_delante_joint" type="continuous">
    <limit lower="0" upper="0" effort="100.00000" velocity="100.00000"/>
    <origin rpy="-1.57080 0.00000 0.00000" xyz="0.00000 0.02000 0.02000"/>
    <parent link="Cylinder_link"/>
    <child link="Cube.001_link"/>
    <axis xyz="0.00000 1.00000 0.00000"/>
  </joint>
  <joint name="Cube_derecha_detras_joint" type="continuous">
    <limit lower="0" upper="0" effort="100.00000" velocity="100.00000"/>
    <origin rpy="-1.57080 0.00000 0.00000" xyz="-0.00000 0.02000 0.02000"/>
    <parent link="Cylinder.002_link"/>
    <child link="Cube.004_link"/>
    <axis xyz="0.00000 1.00000 0.00000"/>
  </joint>
  <joint name="Cube_derecha_medio_joint" type="continuous">
    <limit lower="0" upper="0" effort="100.00000" velocity="100.00000"/>
    <origin rpy="-1.57080 0.00000 0.00000" xyz="0.00000 0.02000 0.02000"/>
    <parent link="Cylinder.001_link"/>
    <child link="Cube.002_link"/>
    <axis xyz="0.00000 1.00000 0.00000"/>
  </joint>
  <joint name="Cube_izquierda_delante_joint" type="continuous">
    <limit lower="0" upper="0" effort="100.00000" velocity="100.00000"/>
    <origin rpy="-1.57080 0.00000 0.00000" xyz="0.00000 0.02000 -0.02000"/>
    <parent link="Cylinder.004_link"/>
    <child link="Cube.006_link"/>
    <axis xyz="0.00000 1.00000 0.00000"/>
  </joint>
  <joint name="Cube_izquierda_detras_joint" type="continuous">
    <limit lower="0" upper="0" effort="100.00000" velocity="100.00000"/>
    <origin rpy="-1.57080 0.00000 0.00000" xyz="-0.00000 0.02000 -0.02000"/>
    <parent link="Cylinder.005_link"/>
    <child link="Cube.007_link"/>
    <axis xyz="0.00000 1.00000 0.00000"/>
  </joint>
  <joint name="Cube_izquierda_medio_joint" type="continuous">
    <limit lower="0" upper="0" effort="100.00000" velocity="100.00000"/>
    <origin rpy="-1.57080 0.00000 0.00000" xyz="0.00000 0.02000 -0.02000"/>
    <parent link="Cylinder.003_link"/>
    <child link="Cube.005_link"/>
    <axis xyz="0.00000 1.00000 0.00000"/>
  </joint>
  <joint name="Torus.001_link_joint" type="fixed">
    <origin rpy="-1.57080 -1.57080 -3.14159" xyz="-0.00000 0.00000 0.04500"/>
    <parent link="Cone.001_link"/>
    <child link="Torus.001_link"/>
  </joint>
  <joint name="Torus.002_link_joint" type="fixed">
    <origin rpy="-1.57080 -1.57080 -3.14159" xyz="0.00000 0.00000 0.04500"/>
    <parent link="Cone.002_link"/>
    <child link="Torus.002_link"/>
  </joint>
  <joint name="Torus.003_link_joint" type="fixed">
    <origin rpy="-1.57080 -1.57080 -3.14159" xyz="-0.00000 0.00000 0.04500"/>
    <parent link="Cone.003_link"/>
    <child link="Torus.003_link"/>
  </joint>
  <joint name="Torus.004_link_joint" type="fixed">
    <origin rpy="-1.57080 -1.57080 -3.14159" xyz="0.00000 0.00000 0.04500"/>
    <parent link="Cone.004_link"/>
    <child link="Torus.004_link"/>
  </joint>
  <joint name="Torus.005_link_joint" type="fixed">
    <origin rpy="-1.57080 -1.57080 -3.14159" xyz="0.00000 0.00000 0.04500"/>
    <parent link="Cone.005_link"/>
    <child link="Torus.005_link"/>
  </joint>
  <joint name="Torus_link_joint" type="fixed">
    <origin rpy="1.57080 -1.57080 3.14159" xyz="0.00000 0.00000 0.04500"/>
    <parent link="Cone_link"/>
    <child link="Torus_link"/>
  </joint>
  <joint name="derecha_delante_joint" type="continuous">
    <limit lower="0" upper="0" effort="100.00000" velocity="100.00000"/>
    <origin rpy="1.57080 0.00000 0.00000" xyz="0.10000 -0.08200 -0.05000"/>
    <parent link="Cube_link"/>
    <child link="Cylinder_link"/>
    <axis xyz="0.00000 0.00000 1.00000"/>
  </joint>
  <joint name="derecha_detras_joint" type="continuous">
    <limit lower="0" upper="0" effort="100.00000" velocity="100.00000"/>
    <origin rpy="1.57080 0.00000 0.00000" xyz="-0.10000 -0.08200 -0.05000"/>
    <parent link="Cube_link"/>
    <child link="Cylinder.002_link"/>
    <axis xyz="0.00000 0.00000 1.00000"/>
  </joint>
  <joint name="derecha_medio_joint" type="continuous">
    <limit lower="0" upper="0" effort="100.00000" velocity="100.00000"/>
    <origin rpy="1.57080 0.00000 0.00000" xyz="0.00000 -0.08200 -0.05000"/>
    <parent link="Cube_link"/>
    <child link="Cylinder.001_link"/>
    <axis xyz="0.00000 0.00000 1.00000"/>
  </joint>
  <joint name="izquierda_delante_joint" type="continuous">
    <limit lower="0" upper="0" effort="100.00000" velocity="100.00000"/>
    <origin rpy="1.57080 0.00000 0.00000" xyz="0.10000 0.08200 -0.05000"/>
    <parent link="Cube_link"/>
    <child link="Cylinder.004_link"/>
    <axis xyz="0.00000 0.00000 1.00000"/>
  </joint>
  <joint name="izquierda_detras_joint" type="continuous">
    <limit lower="0" upper="0" effort="100.00000" velocity="100.00000"/>
    <origin rpy="1.57080 0.00000 0.00000" xyz="-0.10000 0.08200 -0.05000"/>
    <parent link="Cube_link"/>
    <child link="Cylinder.005_link"/>
    <axis xyz="0.00000 0.00000 1.00000"/>
  </joint>
  <joint name="izquierda_medio_joint" type="continuous">
    <limit lower="0" upper="0" effort="100.00000" velocity="100.00000"/>
    <origin rpy="1.57080 0.00000 0.00000" xyz="0.00000 0.08200 -0.05000"/>
    <parent link="Cube_link"/>
    <child link="Cylinder.003_link"/>
    <axis xyz="0.00000 0.00000 1.00000"/>
  </joint>
  <link name="Cone.001_link">
    <inertial>
      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
      <origin rpy="0.00000 0.00000 0.00000" xyz="0.00000 0.00000 -0.02500"/>
      <mass value="0.01000"/>
    </inertial>
    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
  </link>
  <link name="Cone.002_link">
    <inertial>
      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
      <origin rpy="0.00000 0.00000 0.00000" xyz="0.00000 0.00000 -0.02500"/>
      <mass value="0.01000"/>
    </inertial>
    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
  </link>
  <link name="Cone.003_link">
    <inertial>
      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
      <origin rpy="0.00000 0.00000 0.00000" xyz="0.00000 0.00000 -0.02500"/>
      <mass value="0.01000"/>
    </inertial>
    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
  </link>
  <link name="Cone.004_link">
    <inertial>
      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
      <origin rpy="0.00000 0.00000 0.00000" xyz="0.00000 0.00000 -0.02500"/>
      <mass value="0.01000"/>
    </inertial>
    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
  </link>
  <link name="Cone.005_link">
    <inertial>
      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
      <origin rpy="0.00000 0.00000 0.00000" xyz="0.00000 0.00000 -0.02500"/>
      <mass value="0.01000"/>
    </inertial>
    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
  </link>
  <link name="Cone_link">
    <inertial>
      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
      <origin rpy="0.00000 0.00000 0.00000" xyz="0.00000 0.00000 -0.00000"/>
      <mass value="0.01000"/>
    </inertial>
    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
  </link>
  <link name="Cube.001_link">
    <inertial>
      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
      <origin rpy="0.00000 0.00000 0.00000" xyz="0.00000 -0.00000 0.00000"/>
      <mass value="0.01000"/>
    </inertial>
    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
  </link>
  <link name="Cube.002_link">
    <inertial>
      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
      <origin rpy="0.00000 0.00000 0.00000" xyz="0.00000 -0.00000 0.00000"/>
      <mass value="0.01000"/>
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

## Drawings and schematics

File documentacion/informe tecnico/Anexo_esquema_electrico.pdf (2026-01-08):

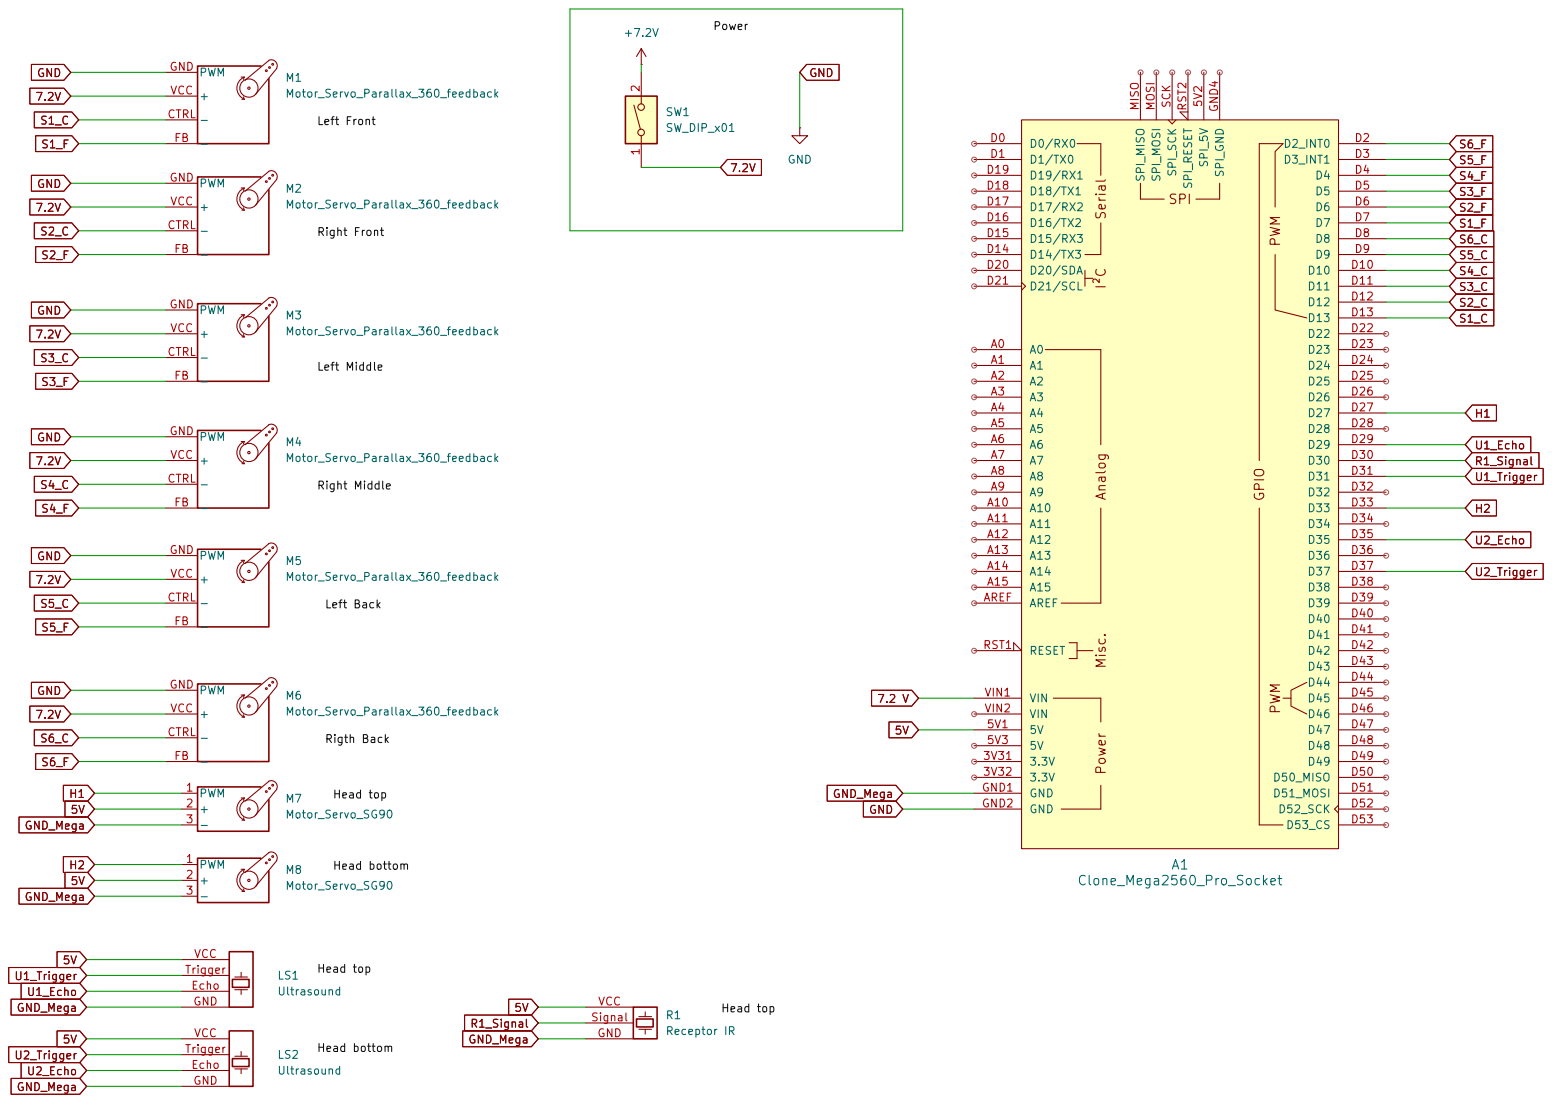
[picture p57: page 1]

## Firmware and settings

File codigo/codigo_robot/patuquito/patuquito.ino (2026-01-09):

// Codigo del robot con motores moviendose


#include <Servo.h>
#include <IRremote.h>

// states
int state;
int direccion;

enum states {
  INICIO = 0,
  PRUEBA1 = 1,
  PRUEBA2 = 2,
};

enum direcciones {
  RECTO = 0,
  GIRO_DERECHA = 1,
  GIRO_IZQUIERDA = 2,
  GIRO_90_DERECHA = 3,
  GIRO_90_IZQUIERDA = 4,
  RECTO_LARGO = 5,
  PARAR = 6,
  RETROCEDER = 7,
};

// mando
#define CODIGO_BOTON_1 0x2FFA00
#define CODIGO_BOTON_2 0x2EFA20
#define IR_PIN 30

// tiempo antirrebote
unsigned long t_antirrebote = 500;

// ultrasonic sensor cabeza1 (arriba)
#define TRIG1 31
#define ECHO1 29
long distancia_pared;

// ultrasonic sensor cabeza2 (abajo)
#define TRIG2 37
#define ECHO2 35

// servo cabeza1 (arriba)
Servo HeadServo1;
int servo1_angle = 0;

// servo cabeza2 (abajo)
Servo HeadServo2;
int servo2_angle = 0;

// leds
#define LED_AZUL 24
#define LED_AMARILLO 25
#define LED_VERDE 26

// botones
#define BOTON_1 22
#define BOTON_2 23
long interrupcion1_start = 0, interrupcion2_start = 0;

// servos
const int numServos = 6;
const int numMitadServos = 3;
Servo servos[numServos];

// num vueltas
const int vueltas90Derecha = 3;
const int vueltas90Izquierda = 3;
const int vueltasRectoLargo = 5;

// Pines PWM para mover los servos
const int pwmPins[numServos] = {13, 11, 9, 12, 10, 8}; // 13, 11, 9 derecha -> 12, 10, 8 izquierda

// Pines para leer feedback PWM
const int fbPins[numServos] = {7, 5, 3, 6, 4, 2};

// Variables para contar vueltas
float prevAngle[numServos] = {0,0,0,0,0,0};
int vueltas[numServos] = {0,0,0,0,0,0};

// 
bool robot_inicializado = false;
int angle_to_turn = 0;
bool obtacle_detected = false, wall_detected = false, first_time = true;
bool valor_led_amarillo = HIGH;
int led_parpadeo_counter = 0;
unsigned long angulos_laser_check[] = {45, 50, 90, 130, 135};
int wall_counter = 0;
unsigned long time_start_count, prueba1_time_start;
bool esquivar_derecha;


void setup() {
  Serial.begin(9600);

  // estado inicial
  state = INICIO;
  direccion = RECTO;

  // ultrasonic sensor cabeza1 (arriba)
  pinMode(TRIG1, OUTPUT);
  pinMode(ECHO1, INPUT);
  digitalWrite(TRIG1, LOW);

  // ultrasonic sensor cabeza2 (abajo)
  pinMode(TRIG2, OUTPUT);
  pinMode(ECHO2, INPUT);
  digitalWrite(TRIG2, LOW);

  // servo
  HeadServo1.attach(27);
  HeadServo2.attach(33);

  // leds
  pinMode(LED_AZUL, OUTPUT);
  pinMode(LED_AMARILLO, OUTPUT);
  pinMode(LED_VERDE, OUTPUT);

  // Inicializar servos
  for(int i=0;i<numServos;i++){
    servos[i].attach(pwmPins[i]);
  }

  // mando
  IrReceiver.begin(IR_PIN, ENABLE_LED_FEEDBACK);
}


void loop() {
  // posicion de inicio
  if (state == INICIO) {
    if (!robot_inicializado) {
      posicion_de_inicio();

    } else {
      digitalWrite(LED_VERDE, HIGH);
      digitalWrite(LED_AZUL, LOW);
      digitalWrite(LED_AMARILLO, LOW);
      checkbotones();
      checkmando();
      time_start_count = millis();
    } 
    
  // prueba 1 
  } else if (state == PRUEBA1) {
    if (((millis() - prueba1_time_start) / 1000) < 60) {
      prueba1();
    } else {
      direccion = PARAR;
      state = INICIO;
    }

  // prueba 2
  } else if (state == PRUEBA2) {
    prueba2();
  }

  if (direccion == PARAR) {
    controlar_motores();
    checkbotones();
  } 
}  

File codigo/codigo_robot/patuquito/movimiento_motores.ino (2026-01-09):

void movimiento_recto() { // Avanzar recto indeterminadamente
  for(int i=0; i<numMitadServos; i++) { 
    servos[i].write(70);
  }
  for(int i=numMitadServos; i<numServos; i++) {
    servos[i].write(110);
  }
}


void movimiento_retroceder() { // retroceder
  for(int i=0; i<numMitadServos; i++) { 
    servos[i].write(110);
  }
  for(int i=numMitadServos; i<numServos; i++) {
    servos[i].write(70);
  }
}


void movimiento_parar() { // Parar
  for(int i=0; i<numServos; i++) {
    servos[i].write(90); 
  }
}


void movimiento_giro_derecha() { // Girar hacia la derecha
  for(int i=0; i<numServos; i++) {
    servos[i].write(110); 
  }
}


void movimiento_giro_izquierda() { // Girar hacia la izquierda
  for(int i=0; i<numServos; i++) {
    servos[i].write(70); 
  }
}


void movimiento_recto_largo() {
  for (int i=0; i<numServos; i++) {
    vueltas[i] = 0;
  }
  bool todosListos = false;

  while (!todosListos) {
    for(int i=0; i<numServos; i++) { // Girar vueltasRectoLargo
      if(vueltas[i] < vueltasRectoLargo) {
        servos[i].write(110);
      } else {
        servos[i].write(90);
      }
    }

    delay(10);

    for(int i=0; i<numServos; i++) { // Leer feedback y actualizar vueltas
      float angle = readServoPWM(fbPins[i], prevAngle[i]);

      if(angle < 0) angle += 180;   // normaliza a 0-180
      if(prevAngle[i] < 0) prevAngle[i] += 180;

      if(prevAngle[i] > 90 && angle < 90) { // contar vueltas
        vueltas[i]++;
        Serial.print("Servo ");
        Serial.print(i+1);
        Serial.print(" vueltas: ");
        Serial.println(vueltas[i]);
      }
      prevAngle[i] = angle;
    }

    todosListos = true; // Comprobar si todos los servos ya dieron vueltasRectoLargo
    for(int i=0; i<numServos; i++) {
      if(vueltas[i] < vueltasRectoLargo) todosListos = false;
    }
  }
}

void movimiento_giro_90_derecha() {
  for (int i=0; i<numServos; i++){
    vueltas[i] = 0;
  }
  bool todosListos = false;

  while (!todosListos) {
    for(int i=numMitadServos; i<numServos; i++) { // Girar vueltas90Derecha
      if(vueltas[i] < vueltas90Derecha) {
        servos[i].write(110);
        servos[i-3].write(70);
      } else {
        servos[i].write(90);
        servos[i-3].write(90);
      }
    }

    delay(10);

    for(int i=0; i<numServos; i++) { // Leer feedback y actualizar vueltas
      float angle = readServoPWM(fbPins[i], prevAngle[i]);

      if(angle < 0) angle += 180;   // normaliza a 0-180
      if(prevAngle[i] < 0) prevAngle[i] += 180;

      if (i >= numMitadServos) {
        if(prevAngle[i] > 90 && angle < 90) { // contar vueltas
          vueltas[i]++;
          Serial.print("Servo ");
          Serial.print(i+1);
          Serial.print(" vueltas: ");
          Serial.println(vueltas[i]);
        }
      }
      prevAngle[i] = angle;
    }

    todosListos = true; // Comprobar si todos los servos ya dieron vueltas90Derecha
    for(int i=numMitadServos; i<numServos; i++) {
      if(vueltas[i] < vueltas90Derecha) todosListos = false;
    }
  }
}

void movimiento_giro_90_izquierda(){
  for (int i=0; i<numServos; i++) {
    vueltas[i] = 0;
  }
  bool todosListos = false;

  while (!todosListos) {
    for(int i=0; i<numMitadServos; i++) { // Girar vueltas90Izquierda
      if(vueltas[i] < vueltas90Izquierda) {
        servos[i].write(110);
        servos[i+3].write(70);
      } else {
        servos[i].write(90);
        servos[i+3].write(90);
      }
    }

    delay(10);

    for(int i=0; i<numServos; i++) { // Leer feedback y actualizar vueltas
      float angle = readServoPWM(fbPins[i], prevAngle[i]);

      if(angle < 0) angle += 180;   // normaliza a 0-180
      if(prevAngle[i] < 0) prevAngle[i] += 180;

      if (i < numMitadServos) {
        if(prevAngle[i] > 90 && angle < 90) { // contar vueltas
          vueltas[i]++;
          Serial.print("Servo ");
          Serial.print(i+1);
          Serial.print(" vueltas: ");
          Serial.println(vueltas[i]);
        }
      }
      prevAngle[i] = angle;
    }

    todosListos = true; // Comprobar si todos los servos ya dieron vueltas90Izquierda
    for(int i=0; i<numMitadServos; i++) {
      if(vueltas[i] < vueltas90Izquierda) todosListos = false;
    }
  }
}

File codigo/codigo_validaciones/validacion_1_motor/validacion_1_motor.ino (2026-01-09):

// Este codigo comprueba un servo de 5 vueltas
// El servo deja de girar cuando ha completado 5 vueltas

// Para comprobar otro motor, hay que cambiar el numero en
// const int pwmPins[numServos] = {13}; y en const int fbPins[numServos] = {7};
// por el del motor correspondiente

// posicion:

// izquierda delante 12 -> 6
// izquierda medio 10 -> 4
// izquierda detras 8 -> 2

// derecha delante 13 -> 7
// derecha medio 11 -> 5
// derecha detras 9 -> 3

#include <Servo.h>


const int numServos = 1;

// Pines PWM para mover los servos
const int pwmPins[numServos] = {13};

// Pines para leer feedback PWM
const int fbPins[numServos] = {7};

Servo servos[numServos];

// Variables para contar vueltas
float prevAngle[numServos] = {0};
int vueltas[numServos] = {0};
const int maxVueltas = 5;

// Función para leer el ángulo del feedback PWM
float readServoPWM(int pin, float lastAngle){
  long dur = pulseIn(pin, HIGH, 25000); // timeout 25 ms
  if(dur == 0) return lastAngle; // si no hay pulso, retorna anterior
  // Mapear 1000–2000 us a 0–180°
  float angle = map(dur, 1000, 2000, 0, 180);
  return angle;
}

void setup(){
  Serial.begin(9600);

  // Inicializar servos
  for(int i=0;i<numServos;i++){
    servos[i].attach(pwmPins[i]);
  }
}

void loop(){
  for(int i=0;i<numServos;i++){
    // Si no alcanzó las 5 vueltas, girar hacia adelante
    if(vueltas[i] < maxVueltas){
      servos[i].write(160); // máximo hacia adelante
    } else {
      servos[i].write(90);  // detener servo
    }
  }

  delay(10); // pequeña pausa para estabilidad

  // Leer feedback y actualizar vueltas
  for(int i=0;i<numServos;i++){
    float angle = readServoPWM(fbPins[i], prevAngle[i]);

    if(angle < 0) angle += 180;   // normaliza a 0-180
    if(prevAngle[i] < 0) prevAngle[i] += 180;

    // Detectar cruce de 180° → 0° para contar vueltas
    if(prevAngle[i] > 90 && angle < 90){
      vueltas[i]++;
      Serial.print("Servo ");
      Serial.print(i+1);
      Serial.print(" vueltas: ");
      Serial.println(vueltas[i]);
    }

    prevAngle[i] = angle;
  }

  // Comprobar si todos los servos ya dieron 5 vueltas
  bool todosListos = true;
  for(int i=0;i<numServos;i++){
    if(vueltas[i] < maxVueltas) todosListos = false;
  }

  if(todosListos){
    Serial.println("El servo completo 5 vueltas.");
    while(1){
      // detener todo
      for(int i=0;i<numServos;i++) servos[i].write(90);
      delay(1000);
    }
  }
}

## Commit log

2026-01-09 validacion motores
2026-01-09 intento de simulacion
    [oroga_patucos.blend, oruga.blend, oruga.urdf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]
